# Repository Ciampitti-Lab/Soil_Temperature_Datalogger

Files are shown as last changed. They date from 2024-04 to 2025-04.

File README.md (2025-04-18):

# Network of Temperature Dataloggers

## List of Contents

1. [Objective](#objective)
2. [Data logger working flow](#data-logger-working-flow)
3. [List and bill of Materials](#list-and-bill-of-materials)
4. [Circuit Boards and instructive images](#circuit-boards-and-instructive-images)
5. [Algorithm for Arduino](#algorithm-for-arduino)
6. [Algorithm for LILYGO TTGO](#algorithm-for-lilygo-ttgo)
6. [3D Files](#3d-files)
7. [Necessry modifications](#necessary-modifications)
8. [Points to pay attention](#points-to-pay-attention)

---

## Contributors

- Gustavo Nocera Santiago ([@GustavoSantiago113](https://github.com/GustavoSantiago113))
  
---

## Objective
Develop a data logger to collect temperature data in an inside environment using Arduino, LILYGO TTGO and temperature sensors. It works connected to the power source and saves the sensor data along with the date and time into remote and local databases.

---

## Data logger working flow
Into a loop that repeats every n amount of time (configured by the user, with a minimum of 1 minute), the sensors get the temperature value (on a delay of 35 milliseconds between each sensor reading) and send the data to a LILYGO TTGO board. This board will send the data to a MongoDB database on the internet and store the data in a .txt file inside a microSD card. Along with the sensors' read data, the datalogger ID, date and time are also stored in the databases.

The final .txt file is a line per reading with ID, sensors' data, and date-time all separated by commas.

To send data to the remote database, an API can be used. This [Python API](https://github.com/GustavoSantiago113/TempDataLogger_API) was developed for this purpose. It sends the data and pulls it to be used in a [Visualization tool](https://github.com/GustavoSantiago113/TempVis)

---

## List and bill of Materials

| Material | Amount | Description | Price (USD) |
|--- | --- | --- | --- |
| Arduino Uno | 1 | This is the brain, where the sensors will be plugged in and information passed to the SD card | 14.99 |
| Sensors DS18B20 + Resistor | 1 (minimum) | They will read the soil temperature | 2.32 |
| LoRa Board | 1 | Send the data from the datalogger to the LILYGO board | 11.45 |
| RTC Watch + Coin Battery | 1 | Provides the minute/hour/date/month/year | 2.6 |
| 3D printed enclosures | 96g | To protect everything | 1.54 |
| microSD card | 1 | Store data | 4.99 |
| LILYGO TTGO | 1 | Receive data from dataloggers, store in microSD card and send to the MongoDB database | 31.9 |
| PCBs, JST connectors, wires, screws, warning LED and male pins | X | Miscellaneous | 1.6 |
| |  | **Total** | 73.39 |

<br>

---

## Circuit Boards and instructive images
Two circuit boards are made:
1. Connection of all the sensors in parallel. The sensors are connected to the board through a 3-pin JST connector. This board can be connected to the Arduino shield by directly soldering wires in the board or by 3-pin JST connectors;
2. Arduino shield. This board was designed to be connected to the Arduino via male pins and connect the other modules and the sensors' board. 

From the images below, circuit boards were designed in EasyEDA software. The files containing the circuit boards and schematics JSON, and the Gerber files for PCB production are in the folder Circuits.

**<center>Sensors' circuit board**

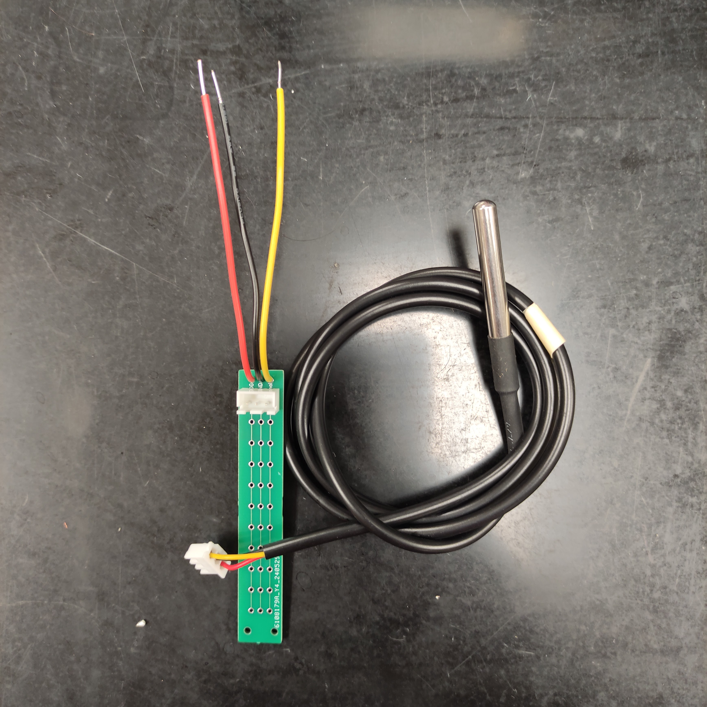
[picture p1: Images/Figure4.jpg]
Sensors' circuit board


**Arduino shield**

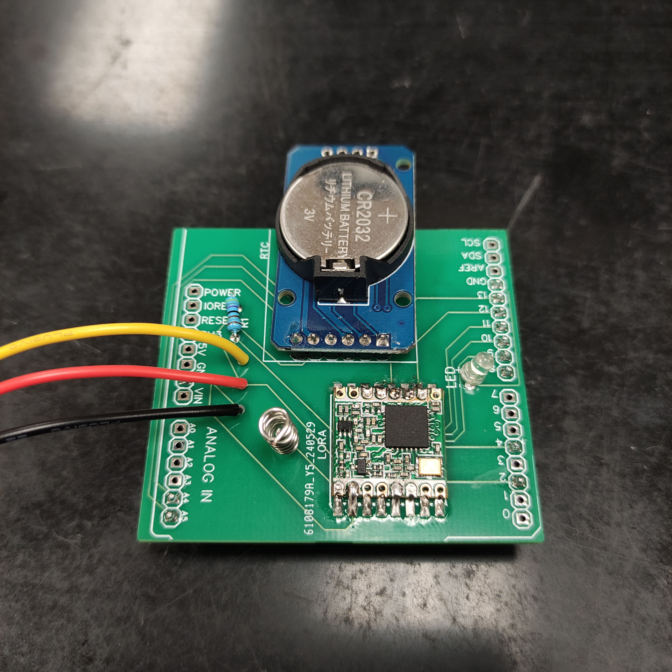
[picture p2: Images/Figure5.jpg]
Arduino shield
</center>

---

## Algorithm for Arduino
The algorithm was made in C++ using Arduino IDE since it is for Arduino. It is located in the Algorithm folder, under the name Emissor. The algorithm is structured as follows:

- Declaration of modifiable variables;

- Inclusion of libraries;

- Declaration of variables;

- Setup, that only runs once when the Arduino is restarted. In this function: 
    1. The RTC and LoRa modules are initialized.
    2. The sensors are counted, located and displayed on the screen the hexadecimal address of each one.

- Loop, that keeps running. In this function:
    1. The date and time information are stored in a variable.
    2. The temperature data are obtained, displayed, and stored in an array.
    3. The data is sent to LILYGO via LoRa.
    4. The Arduino sleeps for the amount of period selected;

- Function to print the hexadecimal address of each found sensor.

- In the file sendPacket.ino, the function to send the data via LoRa is defined. 

---

## Algorithm for LILYGO TTGO
The algorithm was made in C++ using Arduino IDE and selected the LILYGO TTGO board. Remember to install the board in the IDE and the driver in the computer. It is located in the Algorithm folder, under the names Local_only, Receiver and Remote_only. As the names suggest, the Local_only stores data only locally, the Remote_only stores data only remotely, and the Receiver in both. The algorithms are structured as follows:

- Declaration of modifiable variables;

- Inclusion of libraries;

- Declaration of variables;

- Setup, that only runs once when the Arduino is restarted. In this function: 
    1. The LED screen and LoRa are initialized.
    2. The SD card is detected and initialized.
    3. The Widi is connected.

- Loop, that keeps running. In this function:
    1. Create a variable to parse the received packet from LoRa.
    2. Reads the packet, separating the text received and storing it in variables.
    3. Store the variables in the SD card.
    4. Parse the variables to a JSON format and send them to the MongoDB database.
    5. Display informative content on the LED screen.

- In the file POSTData.ino, there is the function that creates the JSON using the variables and posts it to the API, which will send it to the MongoDB database.

- The SSID and password of the Wifi are stored in the secrets.h file, among the server URL.

---

## 3D Files
Some 3D files were designed by the author in Fusion360 and printed in a 3D printer, some were files obtained from Thingiverse. All the STL files are in the folder "3D Files". They are holders to stick in place and protect the Arduino + sensor's board and the LILYGO TTGO board.

---

## Necessary modifications
It is necessary to modify the Arduino to fit your project requirements.

On Arduino:
    - Line 4: the desired ID of the respective device.
    - Line 5: the number of temperature sensors you are connecting to this device.
    - Line 6: the time between readings, in seconds.
    - Line 7: the frequency of the LoRa module you are using.

On LILYGO:
    - Line 4: the file of the .txt document on the SD card. It is necessary to keep the "/" and the ".txt".
    - Line 5: the frequency of the LoRa module you are using.
    - In secret.h, set the SSID (WiFi network name), and the password. Also, set the server URL, keeping the "/store". This server URL is the http address in which you can access your server.

---

## Points to pay attention

- Insert the SD card in the LILYGO board after uploading the code, otherwise, the uploading will present errors.
- A white LED was inserted to warn of potential errors. If it turns on, check the Serial Monitor, the problem will be declared on the screen.
- After tests, we observed that the LILYGO connects better with 2.4GHz WiFI networks.
- While connecting the sensors in the board, pay attention to keeping the same wire terminals in the same parallel line of the others.

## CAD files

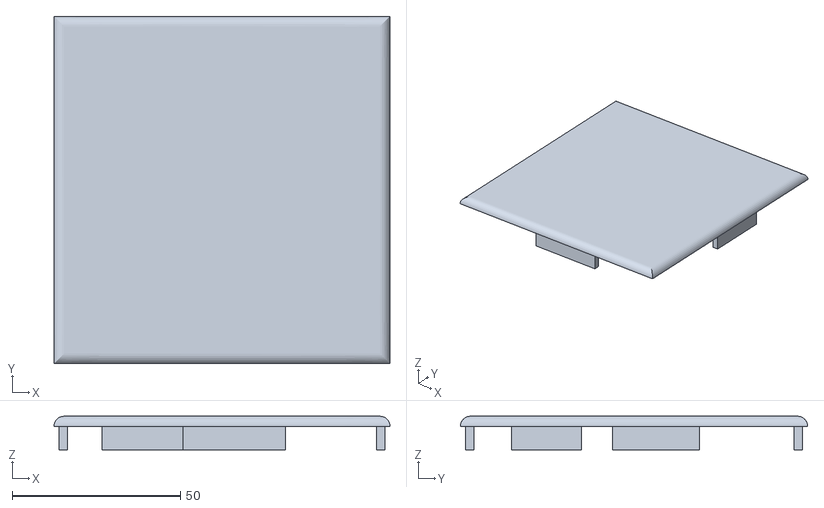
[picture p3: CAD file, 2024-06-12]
3D files/Arduino Cover.stl
99.8 x 103.2 x 10.0

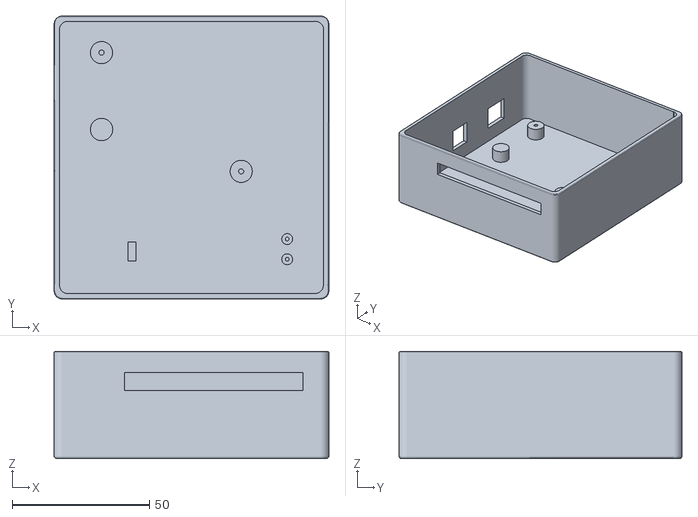
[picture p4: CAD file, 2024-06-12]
3D files/Arduino case.stl
100.0 x 103.0 x 39.1

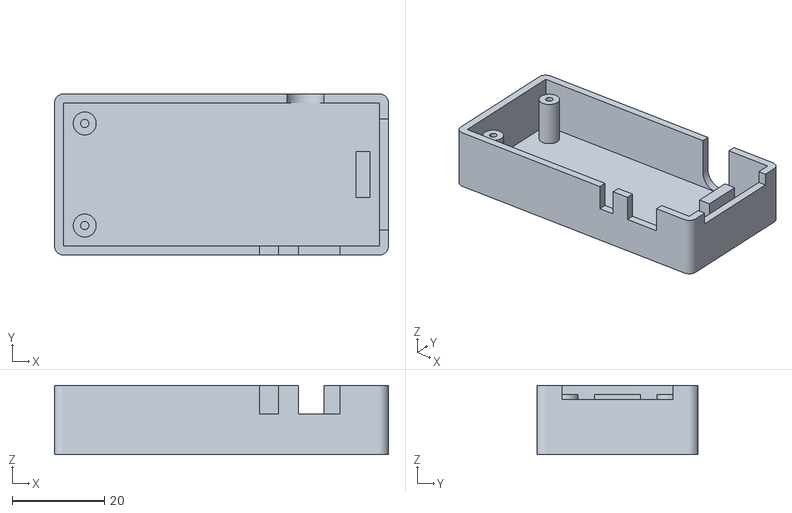
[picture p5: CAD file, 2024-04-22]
3D files/Bottom.stl
72.5 x 35.0 x 15.0

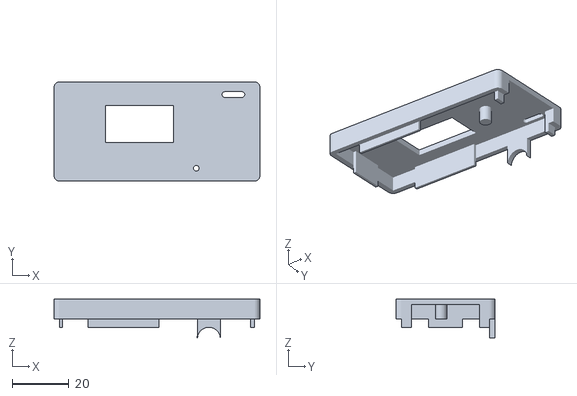
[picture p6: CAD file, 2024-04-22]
3D files/casetop.stl
72.5 x 35.0 x 13.7

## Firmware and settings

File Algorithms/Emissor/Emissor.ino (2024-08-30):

// Author: Gustavo Nocera Santiago

//////// Modify only this parts of the code ///////
int ID = 2; // Device ID - Group number
#define MAX_SENSORS 5 // Define the maximum number of sensors
int timeBetween = 10; // Desired time between measurements, in seconds
long frequency = 915E6; // Lora frequency
float beta_zero = -0.47887; // Beta zero from the calibration linear regression
float beta_one = 1.01903; // Coefficient from the calibration linear regression
///////////////////////////////////////////////////

// Including Libraries
#include <Wire.h>
#include <RTClib.h> // For RTC Clock
#include <OneWire.h> // For Temperature Sensor
#include <DallasTemperature.h> // For Temperature Sensor
#include <LowPower.h> // Put Arduino to sleep and save energy
#include <LoRa.h> // LoRa usage

// Lora pins
#define ss 10
#define rst 9
#define dio0 2

// Variables for RTC
RTC_DS3231 rtc;

// Variables for Temp sensors
const int ONE_WIRE_BUS = 4;

// Setup a oneWire instance to communicate with any OneWire device
OneWire oneWire(ONE_WIRE_BUS);

// Pass oneWire reference to DallasTemperature library
DallasTemperature sensors(&oneWire);

// Number of temperature devices you are using
int numberOfDevices; 

// We'll use this variable to store a found device address
DeviceAddress tempDeviceAddress[MAX_SENSORS];
int foundSensors = 0;
int number_sensors = MAX_SENSORS;

// Warning LED
#define LED_PIN 8

void setup() {

  pinMode(LED_PIN, OUTPUT);

  Serial.begin(9600);

  // Clock
  if (! rtc.begin())
  {
    Serial.println("Clock module not found!");
    digitalWrite(LED_PIN, HIGH);
    while(1);
    
  }
  //rtc.adjust(DateTime(F(__DATE__), F(__TIME__))); //Upload code once with this line uncommented so the clock is adjusted, then coment this line and upload again
  LoRa.setPins(ss, rst, dio0);

  // LoRa begin
  if (LoRa.begin(frequency)) {
    Serial.println("Starting LoRa success!");
    delay(500);
  }else{
    Serial.println("Starting LoRa Failed!");
    digitalWrite(LED_PIN, HIGH);
    while(1);
  }
  LoRa.setSyncWord(0xF3);

  // Sensors begin
  sensors.begin();

  // locate devices on the bus
  Serial.print("Locating devices...");

  // Grab a count of devices on the wire
  numberOfDevices = sensors.getDeviceCount();
  Serial.print("Found ");
  Serial.print(numberOfDevices, DEC);
  Serial.println(" devices.");

  if (numberOfDevices > MAX_SENSORS) {
      digitalWrite(LED_PIN, HIGH);
      Serial.print("Number of devices higher than set. Please, fix");
      while(1);
  }
  if (numberOfDevices < MAX_SENSORS) {
      digitalWrite(LED_PIN, HIGH);
      Serial.print("Number of devices lower than set. Please, fix");
      while(1);
  }
  
  while (foundSensors < MAX_SENSORS) {
    sensors.begin();
    numberOfDevices = sensors.getDeviceCount();

    for (int i = 0; i < numberOfDevices && foundSensors < MAX_SENSORS; i++) {
      if (sensors.getAddress(tempDeviceAddress[foundSensors], i)) {
        Serial.print("Found device ");
        Serial.print(foundSensors, DEC);
        Serial.print(" with address: ");
        printAddress(tempDeviceAddress[foundSensors]);
        Serial.println();
        foundSensors++; // Increment the counter for found sensors
      } else {
        Serial.print("Found ghost device at ");
        Serial.print(i, DEC);
        Serial.println(", but could not detect address. Check power and cabling");
      }
      
    }
    // If not all sensors are found, delay and then retry
    if (foundSensors < MAX_SENSORS) {
      digitalWrite(LED_PIN, HIGH);
      Serial.println("Not all sensors found. Retrying in 5 seconds...");
      delay(5000);
      foundSensors = 0;
    }
  }

  if(foundSensors == MAX_SENSORS){
    digitalWrite(LED_PIN, LOW);
  }
  
}

void loop() {
  
  // Clock
  DateTime fecha = rtc.now();

  // Send the command to get temperatures
  sensors.requestTemperatures();

  Serial.print(fecha.day());
  Serial.print("/");
  Serial.print(fecha.month());
  Serial.print("/");
  Serial.print(fecha.year());
  Serial.print(", ");
  Serial.print(fecha.hour());
  Serial.print(":");
  Serial.println(fecha.minute());
  
  float package[number_sensors];
  // Loop through each device, print out temperature data
  for(int i=0; i < numberOfDevices && i < MAX_SENSORS; i++) {
    float tempC = sensors.getTempC(tempDeviceAddress[i]);
    Serial.print("Temperature for device: ");
    Serial.print(i, DEC);
    Serial.print(" - ");
    Serial.println(tempC);
    package[i] = beta_zero +  (beta_one * tempC);
    delay(35);
  }

  sendPacket(package, fecha, number_sensors);
  
  for(int i = 0; i<= timeBetween; i++)
  {
     LowPower.powerDown(SLEEP_1S, ADC_OFF, BOD_OFF);
  }

}

// function to print a device address
void printAddress(DeviceAddress deviceAddress) {
  for (uint8_t i = 0; i < 8; i++) {
    if (deviceAddress[i] < 16) Serial.print("0");
      Serial.print(deviceAddress[i], HEX);
  }
}

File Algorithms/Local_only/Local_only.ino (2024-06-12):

// Author: Gustavo N. Santiago

//////// Modify only this parts of the code ///////
#define file_name "/test.txt" // Change "test.txt" to the local database txt file you set before, keeping the "/"
long frequency = 915E6;
///////////////////////////////////////////////////

//Libraries for LoRa
#include <SPI.h>
#include <LoRa.h>

// Libraries for microSD card
#include <SD.h>

//Libraries for OLED Display
#include <Wire.h>
#include <Adafruit_GFX.h>
#include <Adafruit_SSD1306.h>

//Define the pins used by the LoRa transceiver module
#define SCLK 5
#define MISO 19
#define MOSI 27
#define CS 18
#define RST 23
#define DIO0 26

// SD SPI pins
#define SD_CS 13
#define SD_SCK 14
#define SD_MOSI 15
#define SD_MISO 2

//OLED pins
#define OLED_SDA 21
#define OLED_SCL 22 
#define SCREEN_WIDTH 128
#define SCREEN_HEIGHT 64
Adafruit_SSD1306 display(SCREEN_WIDTH, SCREEN_HEIGHT, &Wire, OLED_RST);

// For SD card
File myFile;
SPIClass sd_spi(HSPI);

// Setting up a variable to store data from LoRa
String LoRaData;

void setup() { 

  // Initialize Serial Monitor
  Serial.begin(115200);

  // Initialize OLED
  Wire.begin(OLED_SDA, OLED_SCL);
  if(!display.begin(SSD1306_SWITCHCAPVCC, 0x3c, false, false)) { 
    Serial.println(F("SSD1306 allocation failed"));
    for(;;);
  }

  display.clearDisplay();
  display.setTextColor(WHITE);
  display.display();

  Serial.println("LoRa Receiver Test");
  
  //SPI LoRa pins
  SPI.begin(SCLK, MISO, MOSI, CS);
  LoRa.setPins(CS, RST, DIO0);

  //Initialize LoRa
  if (!LoRa.begin(frequency)) {
    Serial.println("Starting LoRa failed!");
    while (1);
  }

  //Set the specific communication between devices
  LoRa.setSyncWord(0xF3);

  Serial.println("LoRa Initializing OK!");
  display.setCursor(0,10);
  display.println("LoRa Initializing OK!");
  display.display();

  // Initialize microSD card
  sd_spi.begin(SD_SCK, SD_MISO, SD_MOSI, SD_CS);

  if (SD.begin(SD_CS, sd_spi)) {
    display.clearDisplay();
    display.setCursor(0,10);
    display.println("Card initialized.");
    display.display();
    Serial.println("Card initialized.");
  }
  else{
    display.clearDisplay();
    display.setCursor(0,10);
    display.println("Card failed, or not present");
    display.display();
    Serial.println("Card failed, or not present");
    while(1);
  }

}

void loop() {

  // Try to parse packet
  int packetSize = LoRa.parsePacket();

  String id;
  String reading;
  String date;

  if (packetSize) {

    // Read packet
    while (LoRa.available()) {

      LoRaData = LoRa.readStringUntil(':');

      if(LoRaData.endsWith("ID"))
        id = LoRa.readStringUntil(',');
      if(LoRaData.endsWith("Readings"))
        reading = LoRa.readStringUntil(',');
      if(LoRaData.endsWith("DateTime"))
        date = LoRa.readStringUntil(',');

    }

    myFile = SD.open(file_name, FILE_APPEND); 
    myFile.print(id);
    myFile.print(",");
    myFile.print(reading);
    myFile.print(",");
    myFile.print(date);
    myFile.println(",");
    myFile.close();

    // Print RSSI of packet
    int rssi = LoRa.packetRssi();

    // Display information
    display.clearDisplay();
    display.setCursor(0,0);
    display.print("Received packet");

    display.setCursor(0,10);
    display.print("Group:");
    display.setCursor(40,10);
    display.print(id);

    display.setCursor(0,20);
    display.print("RSSI:");
    display.setCursor(50,20);
    display.print(rssi);

    display.setCursor(0,30);
    display.print("Saved data to card");

    display.display();

  }

}

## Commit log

2024-04-11 Good changes
    [#PCBs.dxf, PCBs.dxf, file.csv]
2024-04-22 New 3D files
    [Arduino Uno Holder.stl, Arduino case.stl, Bottom.stl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]
2024-04-25 New printing files
    [Antena.stl, Arduino Cover.stl, Arduino case.stl]
2024-04-30 3D files updates
    [Antena.stl, Antenna base.stl, Antenna cover.stl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]
2024-05-03 STL and PCB changes
    [Arduino case.stl]
2024-05-08 Re-arranging files
    [List of materials.xlsx, file.csv, file.xlsx]
2024-06-05 Changes to Mendeley
    [Arduino Cover.stl, Arduino case.stl]
2024-06-10 Changes in the circuits
